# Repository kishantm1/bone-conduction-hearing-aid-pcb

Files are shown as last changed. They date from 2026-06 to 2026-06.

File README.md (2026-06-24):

# Wearable Bone Conduction Hearing Aid / Headphone PCB  

Wearable bone-conduction hearing aid headphone PCB based on the ESP32-S3, integrating an I2S MEMS microphone input, I2S audio amplifier output, LiPo battery charging, USB-C power/programming support, and a bone-conduction transducer interface. This project focused on end-to-end wearable audio hardware development, including BOM creation, schematic design, PCB layout, and board assembly through JLCPCB. 

## Key Features

- Wearable headphone / hearing aid form factor
- ESP32-S3-based embedded audio platform
- I2S MEMS microphone input for audio capture
- I2S DAC/amplifier output for driving a bone-conduction transducer
- 3.7V battery-powered design

## Hardware Architecture

The board is centered around the ESP32-S3 microcontroller and integrates audio input, audio output, battery charging, power regulation, and programming/debug circuitry into a compact wearable PCB.

- **MCU:** ESP32-S3-WROOM-1
- **Microphone input:** I2S MEMS microphone for audio capture
- **Audio output:** I2S DAC/amplifier for driving the bone-conduction transducer
- **Transducer interface:** 2-pin connector for bone-conduction transducer output
- **Power:** 3.7V LiPo battery with USB-C charging and regulated 3.3V system power
- **Debug/programming:** Boot and reset support circuitry
- **Indicators:** Status LED for board/charging indication

## Schematic

### Power

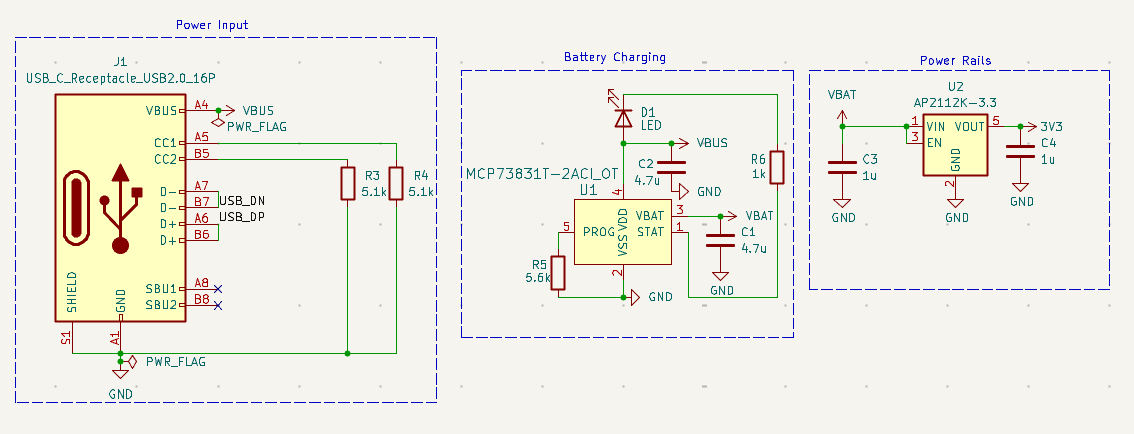
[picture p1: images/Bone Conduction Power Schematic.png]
Bone conduction power schematic


### Processor

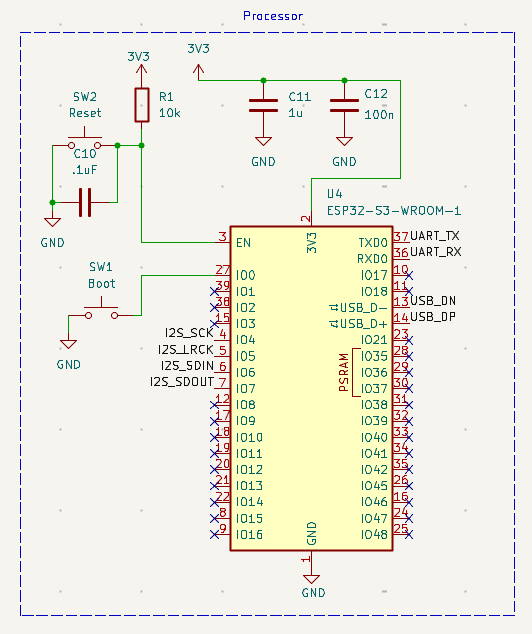
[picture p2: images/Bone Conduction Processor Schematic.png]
Bone conduction processor schematic


### Audio

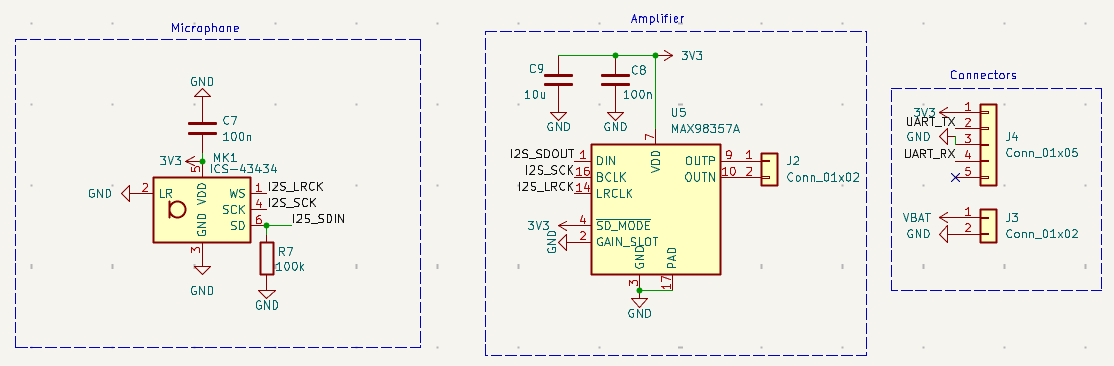
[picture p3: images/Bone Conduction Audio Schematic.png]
Bone conduction audio schematic


## Layout

The 2-layer PCB layout was designed to fit the audio input/output, power, charging, and programming circuitry into a compact wearable form factor.

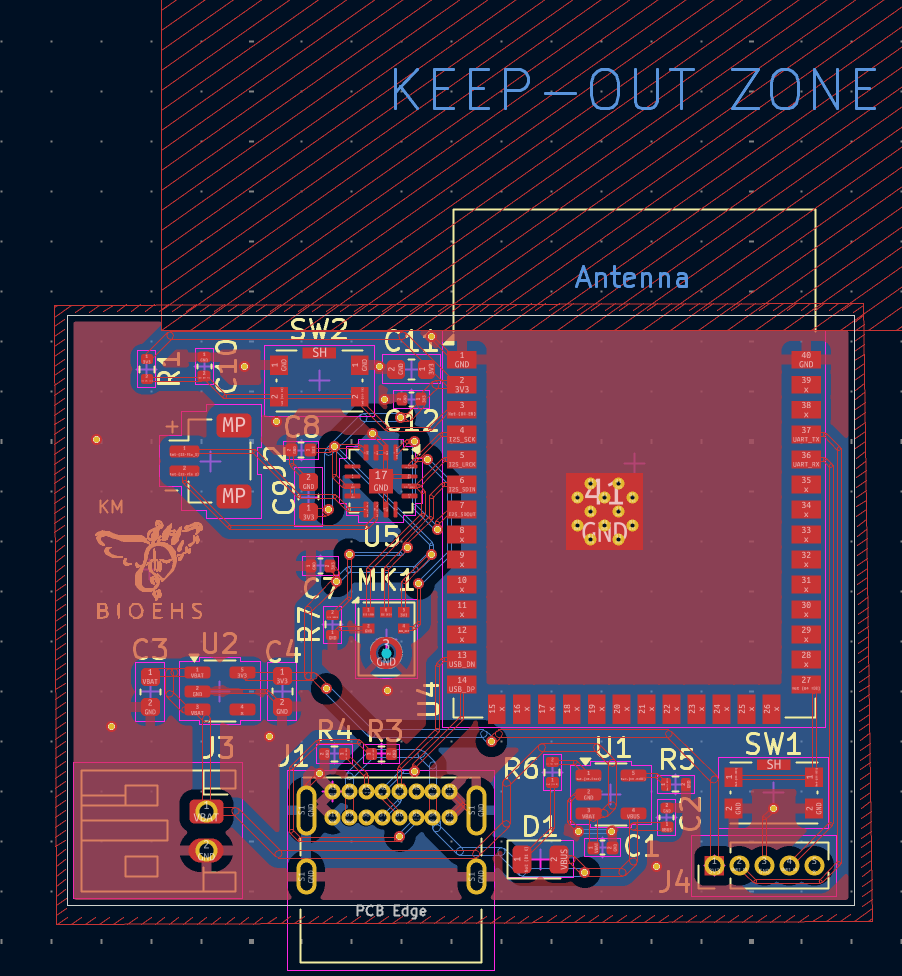
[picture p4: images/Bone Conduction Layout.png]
Bone conduction PCB layout


## 3D View

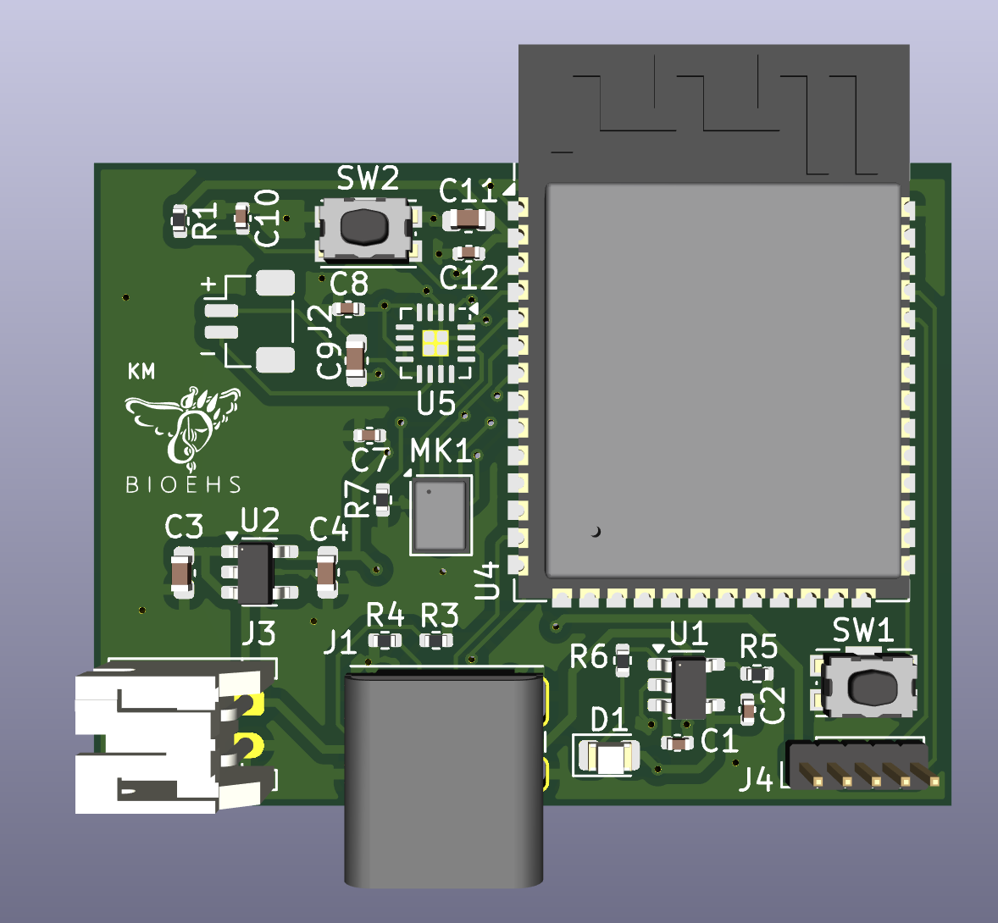
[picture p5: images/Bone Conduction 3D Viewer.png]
Bone conduction PCB 3D view


## Assembled Board

Received assembled bone conduction PCB

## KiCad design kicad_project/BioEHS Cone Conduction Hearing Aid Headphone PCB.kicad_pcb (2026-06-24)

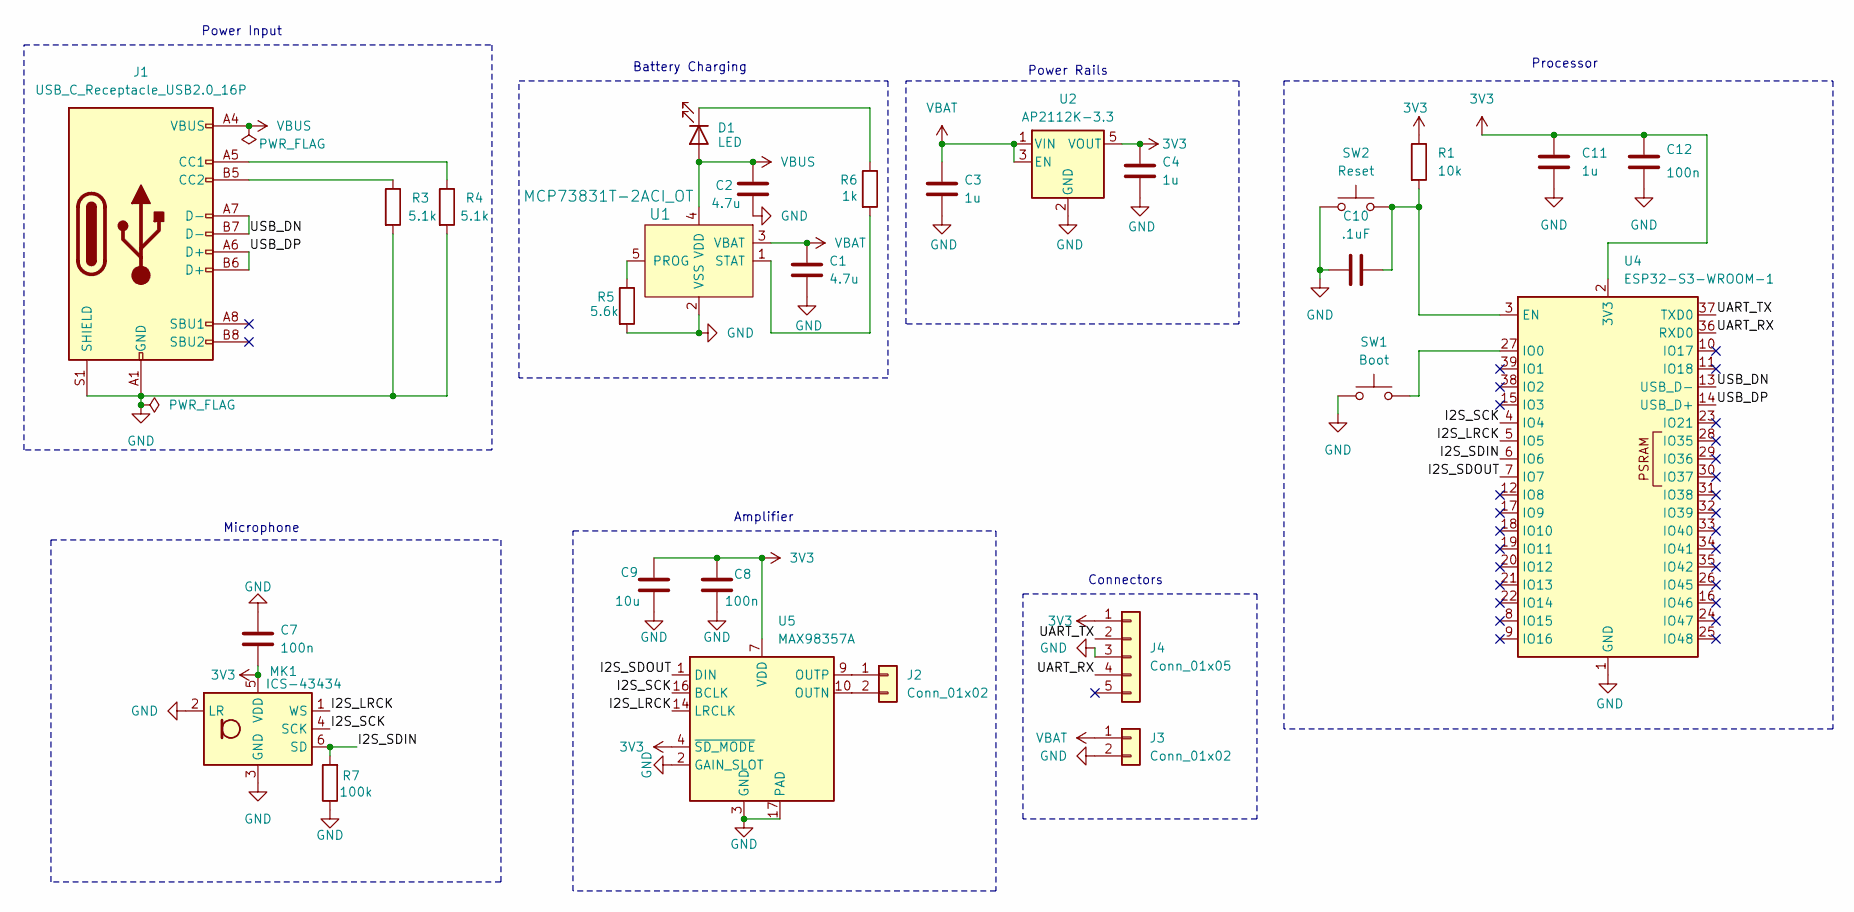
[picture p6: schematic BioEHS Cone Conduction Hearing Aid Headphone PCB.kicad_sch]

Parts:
C1, C2: 4.7u; C_0402_1005Metric
C3, C4, C11: 1u; C_0603_1608Metric
C7, C8, C12: 100n; C_0402_1005Metric
C9: 10u; C_0603_1608Metric
C10: .1uF; C_0402_1005Metric
D1: LED; LED_0805_2012Metric
J1: USB_C_Receptacle_USB2.0_16P; USB_C_Receptacle_GCT_USB4085
J2: Conn_01x02; JST_SH_BM02B-SRSS-TB_1x02-1MP_P1.00mm_Vertical
J3: Conn_01x02; JST_PH_S2B-PH-K_1x02_P2.00mm_Horizontal
J4: Conn_01x05; PinHeader_1x05_P1.27mm_Vertical
MK1: ICS-43434; InvenSense_ICS-43434-6_3.5x2.65mm
R1: 10k; R_0402_1005Metric
R3, R4: 5.1k; R_0402_1005Metric
R5: 5.6k; R_0402_1005Metric
R6: 1k; R_0402_1005Metric
R7: 100k; R_0402_1005Metric
SW1: Boot; SW_Push_1P1T-SH_NO_CK_KMR2xxG
SW2: Reset; SW_Push_1P1T-SH_NO_CK_KMR2xxG
U1: MCP73831T-2ACI_OT; SOT-23-5; MPN MCP73831T-2ACI/OT; Digi-Key_PN MCP73831T-2ACI/OTCT-ND
U2: AP2112K-3.3; SOT-23-5
U4: ESP32-S3-WROOM-1
U5: MAX98357A; TQFN-16-1EP_3x3mm_P0.5mm_EP1.23x1.23mm

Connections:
3V3: C4.1, C7.2, C8.1, C9.1, C11.1, C12.1, J4.1, MK1.5 (VDD), R1.1, U2.5 (VOUT), U4.2 (3V3), U5.4 (~SD_MODE), U5.7 (VDD), U5.8 (VDD)
/I2S_LRCK: MK1.1 (WS), U4.5 (IO5), U5.14 (LRCLK)
/I2S_SCK: MK1.4 (SCK), U4.4 (IO4), U5.16 (BCLK)
/I2S_SDIN: MK1.6 (SD), R7.2, U4.6 (IO6)
/I2S_SDOUT: U4.7 (IO7), U5.1 (DIN)
/UART_RX: J4.4, U4.36 (RXD0)
/UART_TX: J4.2, U4.37 (TXD0)
/USB_DN: J1.A7 (D-), J1.B7 (D-), U4.13 (USB_D-)
/USB_DP: J1.A6 (D+), J1.B6 (D+), U4.14 (USB_D+)
GND: C1.2, C2.2, C3.2, C4.2, C7.1, C8.2, C9.2, C10.1, C11.2, C12.2, J1.A1 (GND), J1.A12 (GND), J1.B1 (GND), J1.B12 (GND), J1.S1 (SHIELD), J3.2, J4.3, MK1.2 (LR), MK1.3 (GND), R3.2, R4.2, R5.2, R7.1, SW1.2, SW2.1, U1.2 (VSS), U2.2 (GND), U4.1 (GND), U4.40 (GND), U4.41 (GND), U5.2 (GAIN_SLOT), U5.3 (GND), U5.11 (GND), U5.15 (GND), U5.17 (PAD)
unnamed: D1.1 (K), R6.1
unnamed: J1.A5 (CC1), R4.1
unnamed: J1.B5 (CC2), R3.1
unnamed: J2.1, U5.9 (OUTP)
unnamed: J2.2, U5.10 (OUTN)
unnamed: R5.1, U1.5 (PROG)
unnamed: R6.2, U1.1 (STAT)
unnamed: C10.2, R1.2, SW2.2, U4.3 (EN)
unnamed: SW1.1, U4.27 (IO0)
VBAT: C1.1, C3.1, J3.1, U1.3 (VBAT), U2.1 (VIN), U2.3 (EN)
VBUS: C2.1, D1.2 (A), J1.A4 (VBUS), J1.A9 (VBUS), J1.B4 (VBUS), J1.B9 (VBUS), U1.4 (VDD)

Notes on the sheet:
Battery Charging
Microphone
Power Rails
Amplifier
Power Input
Connectors
Processor

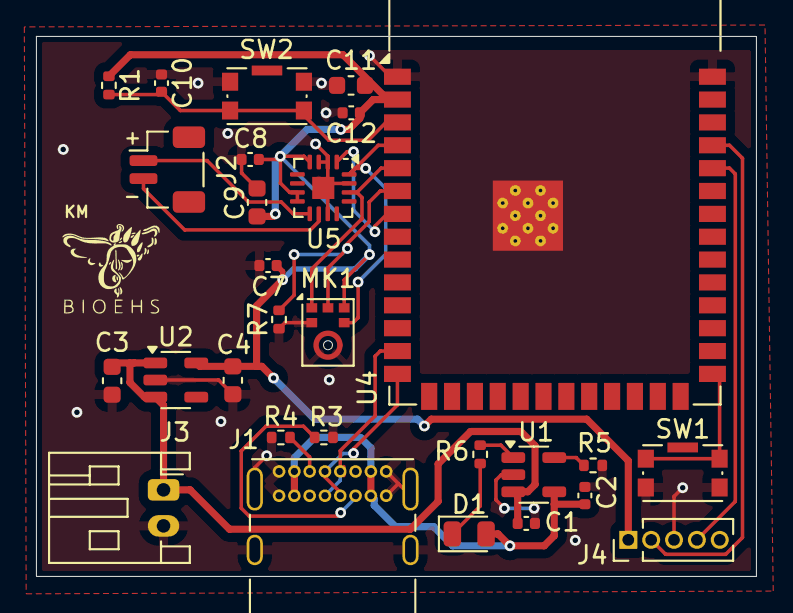
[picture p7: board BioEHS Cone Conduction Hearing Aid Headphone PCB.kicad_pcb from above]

Board: 2 copper layers, 40.0 x 30.0 mm, 28 parts (0 on the bottom side), 21 nets.

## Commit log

2026-06-24 Bone Conduction Board Images
2026-06-24 Create kicad_project
2026-06-24 KiCad Files
